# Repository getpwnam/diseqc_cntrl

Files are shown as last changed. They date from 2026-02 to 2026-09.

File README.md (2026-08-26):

# diseqc_cntrl

Ethernet-connected DiSEqC motor control interface for satellite LNB systems, built around an STM32F407 microcontroller.

## Disclaimer

This project is in development. No hardware or software testing has been performed and use in any way is at your own risk.

## Introduction

Enables remote control of LNB power supply voltage (13 V / 18 V polarization selection), DiSEqC 1.x command generation, and IF signal routing — all manageable over a 10/100 Mbps Ethernet link or USB.

## Repository Structure

The project is intentionally split into separate domains:

1. `hardware/`  
	KiCad schematics, PCB layout, fabrication outputs, and hardware-specific assets.
2. `software/nanoFramework/`  
	Managed application + native integration layer used by this project.
3. `nf-interpreter` (external dependency at build time)  
	The nanoFramework/ChibiOS firmware base is cloned during build and patched with this repository's target files.

See:
- `hardware/README.md`
- `software/README.md`
- `software/nanoFramework/README.md`

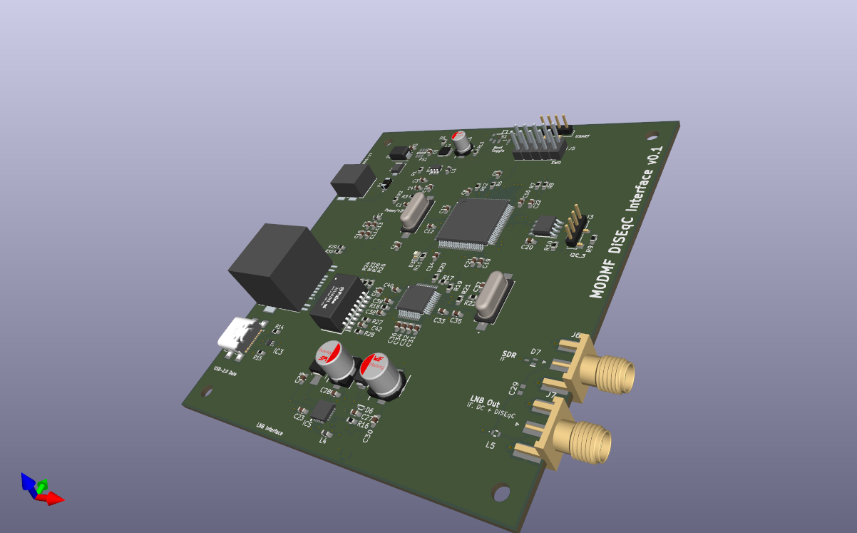
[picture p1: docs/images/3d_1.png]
3D render - top


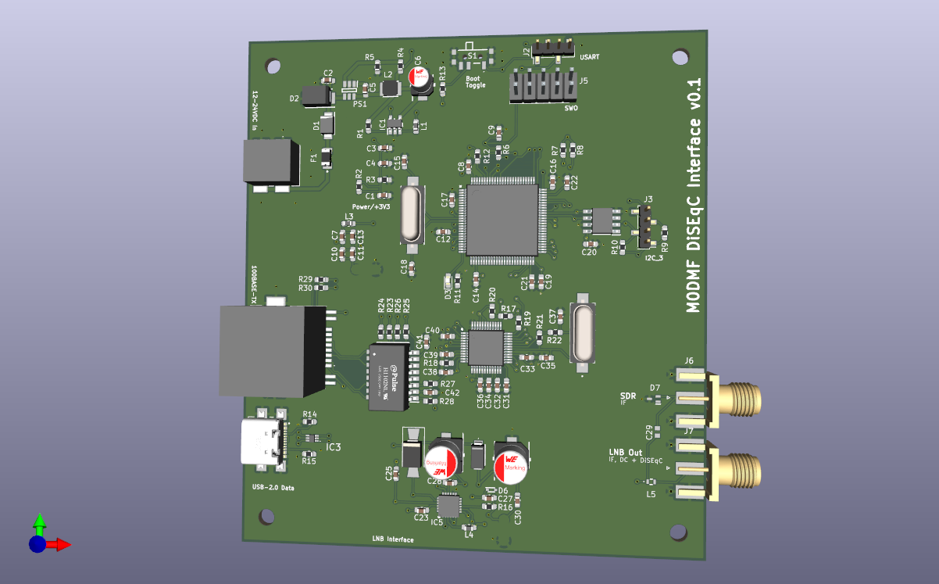
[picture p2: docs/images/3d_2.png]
3D render - perspective


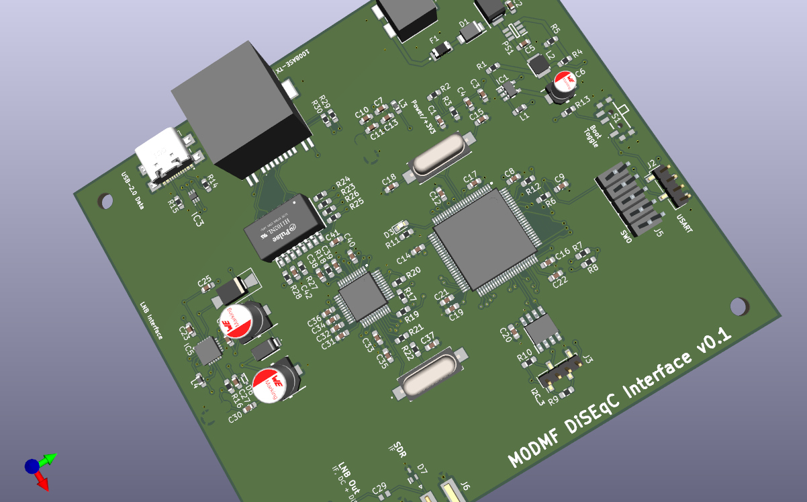
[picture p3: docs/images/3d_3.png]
3D render - bottom


## PCB

4-layer board (F.Cu / In1.Cu / In2.Cu / B.Cu) with split ground planes — digital GND, analog GNDA, and power PGND domains are connected via net ties at controlled star-ground points to minimise noise coupling into the LNB signal path.

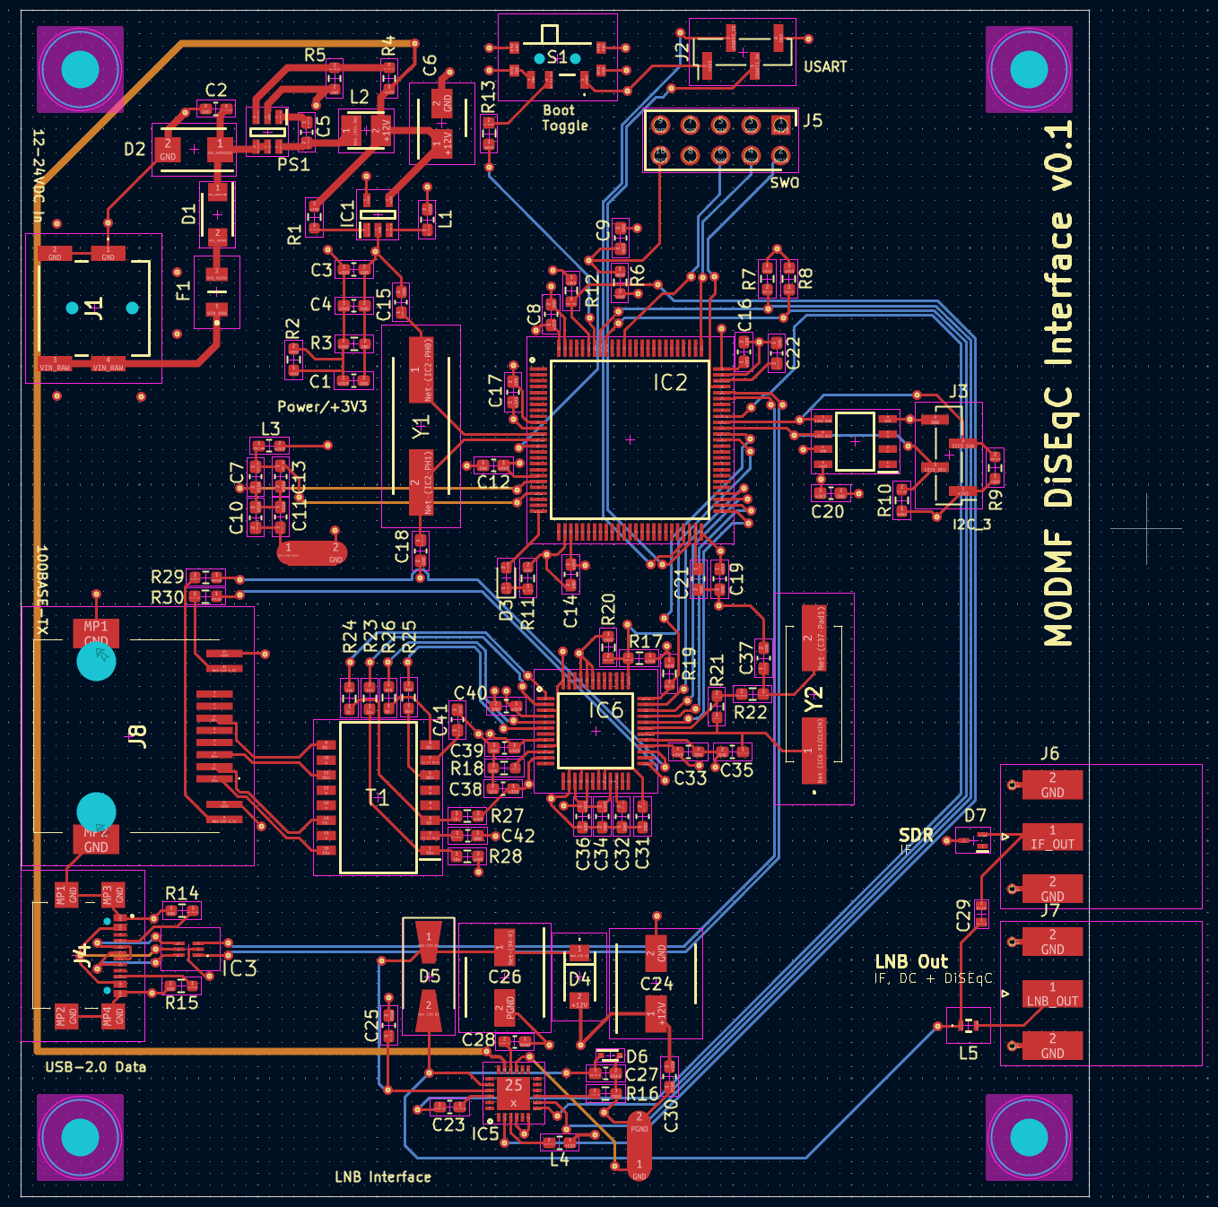
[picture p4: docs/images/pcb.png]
PCB layout


## Hardware Overview

### Microcontroller

- **STM32F407VGT6** (ARM Cortex-M4, 168 MHz, 1 MB Flash, 192 KB RAM, LQFP-100)
- 8 MHz HSE crystal (ABLS-8.000MHZ-20-B-3-H-T) on PH0/PH1 with C15/C18 load capacitors
- Separate filtered +3V3_ANA rail for the on-chip ADC reference
- Status LED (green, 0603)

### Key peripherals used

| Peripheral | Function |
| --- | --- |
| I2C1 | LNBH26PQR LNB supply controller |
| I2C3 | FM24CL16B 16 Kb F-RAM and expansion header |
| Ethernet MAC (RMII) | LAN8742A 10/100 Ethernet PHY |
| TIM4 CH1 | DiSEqC 22 kHz tone generation |
| USART3 | Serial debug / expansion (pin header J2) |
| USB OTG FS | USB 2.0 device (USB-C) |
| SWD | Debug port (2×5 pin header J5) |

### Power Supply

**Input:** Barrel jack (RASM742TRX, 2.1 mm centre-positive)

Protection chain (in order):

1. **F1** — PTC resettable fuse (1812L075/33DR, 0.75 A hold / 33 V)
2. **D2** — SMBJ24D bidirectional TVS (24 V clamp)
3. **D1** — SS14F-HF Schottky diode (reverse polarity protection)

Regulation:

| Stage | Device | Topology | Output |
| --- | --- | --- | --- |
| 1 | PS1 (TPS560430XDBVR) | Synchronous buck (4.3–36 V in) | +12 V (feeds LNBH26PQR) |
| 2 | TPS560200DBVR | Buck (4.5–17 V in) | +3.3 V (digital logic) |

A filtered +3V3_ANA rail is derived from +3.3 V via a ferrite bead for the MCU analog supply.

### LNB Control — LNBH26PQR

- Dual LNB supply regulator with integrated step-up converter (ST LNBH26PQR, QFN-24)
- Powered from the +12 V rail
- Generates switchable 13 V / 18 V output for LNB polarization selection
- Built-in DiSEqC 1.x/2.x 22 kHz tone modulation, driven from TIM4 CH1
- Fault output routed to MCU GPIO
- External boost components: STPS130A Schottky, US1A rectifier, 33 µH inductor, 100 µF bulk caps
- DiSEqC envelope detection via BAT43XV2 small-signal Schottky
- ESD protection on coaxial outputs (RCLAMP0502BATCT)

### Ethernet

- STM32F407 integrated 10/100 Ethernet MAC connected over RMII
- **LAN8742A-CZ-TR** 10/100 Ethernet PHY (Microchip, SQFN-24)
- 25 MHz PHY crystal (ABLS-25.000MHZ-D-FT)
- **J0011D21BNL** RJ45 connector with integrated magnetics and link/activity LEDs

### USB

- **USB4110-GF-A** USB Type-C receptacle (USB 2.0)
- **USBLC6-2P6** ESD protection on D+/D−
- Connected to STM32 USB OTG FS peripheral

### Non-Volatile Storage

- **FM24CL16B-GTR** 16 Kb F-RAM (Infineon, I2C, SOIC-8)
- Unlimited write endurance — stores network configuration, LNB settings, and DiSEqC sequence parameters

### Connectors

| Ref | Type | Purpose |
| --- | --- | --- |
| J1 | Barrel jack (RASM742TRX) | DC power input |
| J2 | 1×4 pin header (2.00 mm) | USART3 serial header (+3V3, TX, RX, GND) |
| J3 | 1×4 pin header (2.00 mm) | I2C3 expansion header (+3V3, SCL, SDA, GND) |
| J4 | USB-C (USB4110-GF-A) | USB 2.0 device |
| J5 | 2×5 pin header (2.54 mm) | SWD debug |
| J6 | SMA edge-mount | IF input from LNB |
| J7 | SMA edge-mount | LNB output (power + DiSEqC + IF) |
| J9 | RJ45 (J0011D21BNL) | 10/100 Ethernet with integrated magnetics and LEDs |
| S1 | SPDT slide switch (PCM12SMTBR) | Mode / power select |

### Test Points

| Ref | Net | Purpose |
| --- | --- | --- |
| TP1 | VIN_FUSED | Input rail after PTC fuse |
| TP2 | +12V | Main regulated 12 V rail |
| TP3 | +3V3 | Main digital logic rail |
| TP4 | VIN_RAW | Input rail before fuse/protection chain |
| TP5 | VIN_PROTECTED | Input rail after TVS and reverse-polarity diode |
| TP6 | +3V3_ANA | Filtered analog 3.3 V rail |
| TP7 | VSSA | Analog ground reference |
| TP8 | /MCU/BOOT0 | MCU BOOT0 strap node |
| TP9 | VBUS | USB VBUS (5 V) |
| TP10 | /MCU/CC1 | USB-C CC1 configuration channel |
| TP11 | /MCU/CC2 | USB-C CC2 configuration channel |
| TP12 | IF_OUT | IF signal path node |
| TP13 | LNB_OUT | LNB output node |
| TP14 | /MCU/LNBH26PQR/LNB_FLT | LNB controller fault signal |

### Protection

| Component | Type | Location |
| --- | --- | --- |
| F1 (1812L075/33DR) | PTC fuse, 0.75 A / 33 V | Power input |
| D2 (SMBJ24D) | 24 V bidirectional TVS | After fuse |
| D1 (SS14F-HF) | Schottky reverse polarity | After TVS |
| IC3 (USBLC6-2P6) | USB ESD clamp | USB D+/D− |
| D7 (RCLAMP0502BATCT) | ESD / CDE clamp | LNB coaxial I/O |

## Design Notes

- 4-layer PCB with split ground planes joined at star-ground net ties
- Predominantly 0603 passives throughout
- 3D models (STEP) provided for all major components
- Gerbers exported to `fab/gerber/`
- All Mouser part numbers embedded in schematic symbols for direct BOM procurement
- Crystal load-capacitor values are documented on schematic and periodically re-validated against crystal load specs and board parasitics

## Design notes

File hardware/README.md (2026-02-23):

# Hardware Domain

This directory contains the board design and fabrication assets for the DiSEqC controller.

## Contents

- `kicad-project/`
  - Source-of-truth schematics and PCB layout.
- `gerber/`
  - Fabrication outputs for PCB manufacturing.
- `nonfree/`
  - Third-party footprints/models/symbols and their licenses.
- `LICENSE.txt`
  - Hardware licensing information.

## Working Rules

- Treat KiCad files in `kicad-project/` as canonical.
- Regenerate Gerbers from the matching KiCad revision before manufacturing.
- Keep hardware-specific docs/assets in `hardware/` to avoid cross-domain drift.

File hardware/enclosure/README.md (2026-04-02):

# 3D Printed Enclosure (OpenSCAD)

This folder contains a first-pass printable enclosure for the DiSEqC controller PCB.

## Files

- `openscad/diseqc_enclosure.scad`
  - Parametric base + lid model.
  - Includes side-wall connector apertures for:
    - J1 barrel jack
    - J4 USB-C
    - J8 RJ45
    - J6/J7 SMA pair

## Known PCB Geometry Source

The enclosure defaults are based on:

- Board outline rectangle in KiCad: 90 x 100 mm
- Connector centroid positions from the PCB layout and production placement data

## Build Steps

1. Open `openscad/diseqc_enclosure.scad` in OpenSCAD.
2. Set `mode = "base"` and export STL.
3. Set `mode = "lid"` and export STL.
4. Slice with your preferred settings.

## Suggested Print Settings

- Material: PETG or ASA for outdoor/temperature resilience
- Layer height: 0.2 mm
- Perimeters: 4
- Top/Bottom layers: 5
- Infill: 20-30% gyroid
- Supports: none for base, optional for lid pocket depending on slicer

## Fit Calibration Workflow

1. Print base only.
2. Test PCB seating on ledges.
3. Check connector alignment in side apertures.
4. Tune these variables in the SCAD file:
   - `J1_y`, `J1_z`, `J1_w`, `J1_h`
   - `J4_y`, `J4_z`, `J4_w`, `J4_h`
   - `J8_y`, `J8_z`, `J8_w`, `J8_h`
   - `J67_y`, `J67_z`, `J67_w`, `J67_h`
5. Re-export and reprint base.
6. Once cutouts align, print lid.

## Notes

- This model intentionally uses PCB edge ledges instead of screw standoffs, because mounting-hole coordinates are not yet defined in this design package.
- If you want screw-down mounting, add hole coordinates from KiCad and convert ledges to standoffs in a follow-up revision.

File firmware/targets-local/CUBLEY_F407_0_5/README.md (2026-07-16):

## STM STM32F4DISCOVERY board

STM STM32F4DISCOVERY board

[Product page](http://www.st.com/en/evaluation-tools/stm32f4discovery.html)

The board used in this community contribution is the STM32F4DISCOVERY board from STM. The board can be purchased from various sources and should be about 20 euros. Further information on this board and links for the user and programming manuals can be found at the product page in ST [website](https://www.st.com/en/evaluation-tools/stm32f4discovery.html).

Some basic information abstracted from ST:

- STM32F407VGT6 microcontroller featuring 32-bit ARM®Cortex®-M4 with FPU core, 1-Mbyte Flash memory, 192-kbyte RAM in an LQFP100 package
- On-board ST-LINK/V2 on STM32F4DISCOVERY (old reference) or ST-LINK/V2-A on STM32F407G-DISC1 (new order code)
- USB ST-LINK with re-enumeration capability and three different interfaces:
  - Debug port
  - Virtual Com port (with new order code only)
  - Mass storage (with new order code only)
- Board power supply: through USB bus or from an external 5 V supply voltage
- External application power supply: 3 V and 5 V
- LIS302DL or LIS3DSH ST MEMS 3-axis accelerometer
- MP45DT02 ST-MEMS audio sensor omni-directional digital microphone
- CS43L22 audio DAC with integrated class D speaker driver
- Eight LEDs:
  - LD1 (red/green) for USB communication
  - LD2 (red) for 3.3 V power on
  - Four user LEDs, LD3 (orange), LD4 (green), LD5 (red) and LD6 (blue)
  - 2 USB OTG LEDs LD7 (green) VBUS and LD8 (red) over-current
- Two push-buttons (user and reset)
- USB OTG FS with micro-AB connector
- Extension header for all LQFP100 I/Os for quick connection to prototyping board and easy probing

## Flashing and debugging

This board has one mini USB connector exposing the embedded ST-Link interface that is used for flashing the nanoFramework firmware and for performing debugging on the nanoCLR code.
The second USB connector (a micro USB one) is used to connect the device with Visual Studio allowing to deploy and debug your C# managed applications.

## ADC configurations

The following ADC channels (and respective GPIO pins) are available to the managed API, in the respective index:

- PC1, ADC1 IN11
- PC2  ADC1 IN12
- PA6  ADC2 IN6
- PA7  ADC2 IN7
- PB0  ADC2 IN8
- Temp Sensor ADC1
- VrefInt ADC1
- Vbatt ADC1

## I2C configurations

I2C buses available:

- I2C1
  - SCL pin: GPIOB_8
  - SDA pin: GPIOB_9

## Floating point

The current build is set to add support for single-precision floating point.
Meaning that `System.Math` API supports only the `float` overloads. The `double` ones will throw a `NotImplementedException`.

## Firmware images (ready to deploy)



## Managed helpers

Checkout the [C# managed helpers](https://github.com/nanoframework/nf-Community-Targets/tree/main/ChibiOS/ST_STM32F4_DISCOVERY/managed_helpers) available for this board.

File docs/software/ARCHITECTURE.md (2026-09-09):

# Architecture Reference

## Purpose

Define the software boundaries, control flow, and ownership for the `software/nanoFramework` domain.

## Current Build Profile

- Target: `M0DMF_CUBLEY_F407`
- Build orchestrator: `toolchain/build-native.sh`
- Networking (`System.Net`): enabled for the device REST API
- Firmware outputs: `build/nanoCLR.bin`, `build/nanoCLR.hex`, `build/nanoCLR.elf`

## Layered Model

1. **Application Layer (C#)**
  - Location: `DiSEqC_Control/`
   - Responsibilities:
     - command routing
     - high-level rotor/LNB workflows
    - REST command and state interface

2. **Interop Layer (C++ bridge)**
   - Location: `nf-native/*_interop.cpp`
   - Responsibilities:
     - expose native functions to managed runtime
     - marshal arguments/results and status codes

3. **Native Driver Layer (C++/ChibiOS integration)**
  - Location: `nf-native/diseqc_native.*`, `nf-native/lnb_control.*`, `nf-native/board_cubley.*`
   - Responsibilities:
     - DiSEqC timing/control primitives
     - LNB I2C control (LNBH26PQR)
     - board-level pin/peripheral configuration

4. **Upstream Runtime Base (external)**
   - Location at build time: cloned `nf-interpreter`
   - Responsibilities:
     - nanoFramework runtime + ChibiOS target machinery
     - linker/toolchain integration

## Runtime Flows

### Control Flow

`Managed command` → `interop` → `native driver` → `board peripheral`

### Build Flow

`docker compose run ... /work/toolchain/build-native.sh` → clone/update `nf-interpreter` → copy static target files into `nf-interpreter/targets/ChibiOS/M0DMF_CUBLEY_F407/` → apply upstream compatibility patches → CMake/Ninja build → copy artifacts to `build/`

## Target File Ownership

All `M0DMF_CUBLEY_F407` target files are statically maintained in this repository under `nf-native/`:

| Directory | Contents |
|---|---|
| `nf-native/` | Board files: `board_cubley.h/cpp`, native drivers, interop sources |
| `nf-native/target-overrides/` | All ChibiOS/nf-interpreter integration files (halconf, chconf, linker scripts, CMakeLists.txt, mcuconf, target_*.c/cpp/h) |

The build script copies these files into the nf-interpreter target directory on each build. No reference-board fallback files are required. For the `cubley-stable` profile, `NF_STATIC_AUDIT=1` is enforced by default to verify this invariant at build time.

### Upstream Patches

The build script applies a small number of compatibility patches to nf-interpreter on each build:

- `CMake/Modules/FindChibiOS.cmake` — removes a duplicate include-path entry that causes double-compilation
- `CMake/binutils.common.cmake` — fixes `arm-none-eabi-size` invocation in generated ninja rules
- `targets/ChibiOS/_nanoCLR/CMakeLists.txt` — resets stale `INTERNAL` cache lists on re-configure
- `src/CLR/Startup/CLRStartup.cpp` — injects Cubley SWD-mailbox diagnostic hooks
- `src/CLR/Core/TypeSystem.cpp` — injects Cubley assembly-resolve diagnostic pointers

The first three are upstream bugs/limitations; the last two are board-specific diagnostics added during bring-up. All patches are idempotent (guarded by `grep -Fq` before applying).

## Hardware Integration Points

- DiSEqC carrier/timing: TIM-based output path (board-configured)
- LNB control: I2C (`LNBH26PQR`)
- Network path: STM32F407 internal Ethernet MAC over RMII with LAN8742A PHY
- Network application interface: REST v2 over HTTP

## Domain Boundaries

- This document describes `software/nanoFramework` only.
- PCB/schematic/fabrication ownership is in `hardware/`.
- `nf-interpreter` is an external dependency; this repo stores integration and build profile decisions, not a full fork layout.

## Related Documents (Software + Debug)

- `../README.md`
- `../debug/TESTING_GUIDE.md`
- `INTEROP_CONTRACT_V1.md`
- `INTEROP_VERSIONING_POLICY.md`
- `DEVICE_API_V2.md`
- `OBSERVABILITY_CONTRACT_V1.md`
- `CONFIGURATION.md`
- `../debug/LNB_I2C_TESTING.md`

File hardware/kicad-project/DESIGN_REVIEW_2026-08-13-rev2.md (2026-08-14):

# DiSEqC Controller Design Review, Revision 2

**Project:** `diseqc_cntrl` (KiCad 10 source, five hierarchical sheets, four-layer PCB)
**Review date:** 2026-08-13
**Review basis:** current unsuffixed KiCad source and current `production/` outputs; previous review conclusions were not used as evidence
**Verdict:** **Not ready for fabrication or assembly release.** No source-backed critical electrical blocker remains: STM32 `VREF+`, the D6 RClamp0502BA low-capacitance pin mode and direct-plane return, Ethernet MDI direction/polarity, RX orphan cleanup, and `REF_CLK` routing/transition stitching have been corrected. Release remains blocked by unresolved controlled impedance, unresolved stock, remaining open-via process requirements, incomplete finish/process metadata, and regeneration/validation of production outputs.

## Critical Findings

| Severity | Issue | Evidence and required action |
|---|---|---|
| High | Controlled impedances do not match interface targets | Raw-file and analytical verification using the declared 0.10 mm, εr=4.5 outer-layer dielectric and 35 um copper gives 45.6 Ω single-ended / approximately 84.9 Ω differential for the 0.12 mm / 0.20 mm-gap Ethernet MDI geometry, versus 100 Ω differential. Current 0.20 mm traces calculate to 36.2 Ω single-ended, affecting nominal 90 Ω USB, 50 Ω RMII, and 75 Ω IF routing. Obtain the fabricator stackup and field-solved geometries, then reroute and constrain each interface. |
| High | Assembly supply is incomplete | InvenTree matched 62 of 64 identity groups, but immediate unallocated stock is below one-board demand for IC1/IC2, IC4, D3–D6, L1–L3, multiple regulator capacitors/resistors, and one of two USB-C connectors. The production BOM has no manufacturer/supplier ordering fields. Resolve stock or purchase coverage and regenerate a traceable assembly BOM. |

## Previous Review Delta

This review was performed from source, production files, local PDFs, and fresh analyzer output before consulting prior reports.

| Status | Item |
|---|---|
| Resolved during review follow-up | IC3 pin 21 `VREF+` and PCB pad 21 now connect to the same `+3.3VA` rail as VDDA. The rail is fed through FB1 and decoupled by C18 (1 uF) and C21 (100 nF), consistent with STM32F407 Figure 52. |
| Resolved during review follow-up | D6 uses the RClamp0502BA low-capacitance one-line mode: pin 2=`IF_OUT`, pin 1=`GND`, and pin 3 open in both schematic and PCB. D6 is adjacent to the J7 launch; pin 2 has a 0.113 mm signal tap, and pin 1 reaches an off-pad 0.8/0.35 mm GND via through 1.10 mm of 0.20 mm F.Cu. The direct-plane return and via-in-pad warnings are resolved. |
| Resolved during review follow-up | All four exposed-pad thermal vias under each of IC1 and IC2 are explicitly bottom-tented (`front no`, `back yes`). Fresh analysis retains the thermal-via adequacy information and no longer reports solder-wicking warnings for these arrays. |
| Resolved during review follow-up | LAN8742 MDI direction and polarity now map directly: `TXP→TD+`, `TXN→TD-`, `RXP→RD+`, and `RXN→RD-`. Auto-MDIX/polarity correction is no longer required to compensate for PCB mapping. |
| Resolved during review follow-up | The isolated 0.508 mm RXN and 0.120 mm RXP B.Cu remnants are removed. Both nets are now F.Cu-only, have no signal vias, form one connected island each, and have no disconnected pads. |
| Resolved during review follow-up | GND stitching vias at both `REF_CLK` transitions now measure 0.950 mm center-to-center from their signal vias, with 0.150 mm copper-edge clearance. Fresh EMC analysis no longer emits `RP-001`. |
| Resolved during review follow-up | TP11, TP12, and TP16–TP24 were removed with their branch copper. This eliminates the IF_OUT, REF_CLK, MDC, MDIO, TX_EN, CRS_DV, and RMII data test branches; no segment terminates at a deleted pad coordinate. `REF_CLK` copper is now 16.344 mm and IF_OUT copper is 24.866 mm. |
| Still open | Controlled-impedance geometry, stock coverage, lifecycle uncertainty, CAM inspection, and physical electrical/thermal validation. |
| Confirmed resolved | L1/L2/L3 now have specific identities; regulator dividers resolve correctly with the manufacturer 1.000 V reference; current production Gerbers and drills are complete. |

## Design Overview

The board contains two LMR36520 bucks, an STM32F407VGT6, LNBH26PQR LNB/DiSEqC supply and IF extraction, LAN8742A RMII Ethernet with a J0011D21BNL integrated-magjack, native USB, FT230XS USB-UART, FM24CL16B FRAM, and SWD. Input protection includes a resettable fuse, reverse-polarity diode, and 24 V TVS. The PCB is 90 mm × 100 mm, 1.6 mm thick, with F.Cu / 0.10 mm prepreg / In1 GND / 1.24 mm core / In2 power / 0.10 mm prepreg / B.Cu.

## Component Summary

| Item | Result |
|---|---:|
| Schematic components | 157 total, 61 unique populated values, 3 intentional DNP |
| PCB footprints | 148, all placed on F.Cu; 121 SMD and 5 THT classified |
| Nets | 178 schematic; 170 PCB |
| Routing | 1,195 segments, 165 vias, zero reported unrouted nets |
| Zones | 7 filled zones; In1 GND is one 97%-filled region |
| Production BOM / placement | 121 populated BOM references; all 121 are positioned; placement also includes test, debug, net-tie, and fiducial references |
| Gerbers | 13 Gerber files plus PTH and NPTH drills; four copper layers, masks, pastes, silks, and edge cuts present |
| Drill output | 234 holes; X2-based classification and layer extents align |

The three cross-analysis “missing PCB” parts are expected: C9 and C10 are optional feedback capacitors marked DNP with no footprints, and R10 is DNP. This is not a synchronization defect.

## Power Tree and Regulator Review

```text
J1 VIN_RAW
  -> F1 resettable fuse -> VIN_FUSED
  -> D1 reverse-polarity protection + D2 24 V TVS -> VIN_PROTECTED
       -> IC1 LMR36520 + L1 33 uH -> +12V
            -> IC6 LNBH26 boost/linear channel -> 13/18 V LNB_OUT + IF extraction
       -> IC2 LMR36520 + L2 6.8 uH -> +3V3
            -> FB1 -> +3.3VA
            -> NT1 -> +3.3VP -> FB2 -> Ethernet 3V3_BEADED
USB J6 VBUS -> FB3 -> FT230_VCC
```

- **IC1:** R1=100 kΩ and R2=9.09 kΩ. With the LMR36520 1.000 V typical FB reference, $V_{OUT}=1.000(1+100/9.09)=12.00\text{ V}$. The analyzer's 7.20 V result used an incorrect heuristic 0.6 V reference and is rejected.
- **IC2:** R3=100 kΩ and R4=43.2 kΩ give $V_{OUT}=3.315\text{ V}$ nominal. The schematic analyzer missed this divider because of topology parsing.
- **Frequency:** LMR36520 is a fixed 400 kHz part per the manufacturer datasheet, not the analyzer's 500 kHz topology default.
- **Capacitance/inductance:** IC2's 6.8 uH and three 22 uF output capacitors agree with the datasheet's 3.3 V quick-start values. IC1's 33 uH and 4×10 uF plus bulk capacitance are plausible for 12 V but require load-transient verification at the actual VIN and load range.
- **LNBH26:** Pin numbering, I2C logic, 10 uH boost inductor, BYP capacitor, output bulk capacitor, and 27 nH/220 pF IF-isolation network are coherent with the local ST datasheet. The analyzer's 12 V/3.3 V I2C domain errors are false positives: SDA/SCL are logic pins rated independently of the IC's power output.

The actual maximum input voltage, rail loads, LNB current profile, and allowed ripple are not specified in the design files. A signed power budget remains required before release.

## PDN Impedance

The analytical model reports minima of 6.85 mΩ for +3V3 (66.6 uF, 1.58 MHz), 1.73 mΩ for +12V (140.2 uF, 1.58 MHz), 78.8 mΩ for +3.3VA (1.1 uF, 7.94 MHz), and 29.3 mΩ for Ethernet 3V3_BEADED (10.2 uF, 2.51 MHz). These are idealized lumped estimates using generic MLCC parasitics; mounting inductance, DC bias, ferrites, and plane spreading are not fully represented. Validate rail impedance/ripple at IC pins under load.

## Power Budget

The automated budget is incomplete and is not accepted quantitatively: it omits STM32 load, external loads, actual LNB output current, and USB operating states, and it carries the rejected 7.201 V IC1 estimate. It identifies the correct main consumers but only assigns 10 mA to LNBH26 and 100 mA to the PHY. Derive worst-case +12V and +3V3 budgets from firmware modes and external loads, then check converter, inductor, diode, trace, and connector margins.

## Power Sequencing

IC1 and IC2 EN pins are tied to `VIN_PROTECTED`, so +12V and +3V3 start together using each LMR36520's internal soft-start. Their open-drain PG pins are tied to GND and intentionally unused. No downstream rail-valid interlock exists; verify MCU brownout/reset behavior and LNB/PHY startup with simultaneous rails.

## Sleep Current Audit

The analyzer reports 1.42 mA always-on and 277.29 mA “realistic” sleep current, but 275.97 mA comes from treating conditional pull-ups as continuously asserted. That result is not credible without GPIO, PHY, FT230, and LNB states. Measure each supported firmware sleep mode; do not use the analyzer number for product power claims.

## Inrush Analysis

The lumped estimate is 1.01 A for 140.2 uF on +12V and 0.22 A for 66.6 uF on +3V3, assuming a 1 ms soft start. The +12V calculation also used the analyzer's incorrect 7.201 V value, so measure startup current and monotonicity at minimum/maximum VIN and with the intended LNB load.

## Analyzer Verification

### Datasheet and Pin Verification

Manufacturer PDFs in `.debug` were used directly. All analyzer-exposed complex components were compared from schematic pin number to PCB pad number: 278 of 284 normalized comparisons matched directly. The six residual names are intentional hierarchy aliases on the UART and duplicated USB-C VBUS pins; no physical pad mismatch was found.

| Device | Verification result |
|---|---|
| IC1/IC2 LMR36520ADDAR | Pins 1–9 and exposed-pad net mapping match TI Table 5-1. Feedback reference corrected to 1.000 V. |
| IC3 STM32F407VGT6 | LQFP100 pin numbering and RMII/USB/SWD alternate-function choices match the ST tables. Pin 21 `VREF+` and PCB pad 21 resolve to `+3.3VA`; C18 (1 uF) and C21 (100 nF) provide local reference decoupling. |
| IC4 FM24CL16B-GTR | SOIC-8 pin map, grounded WP, and I2C connections match the Infineon datasheet. |
| IC5 USBLC6-2P6 | Flow-through D+/D-, GND, and VBUS pin mapping matches the ST application circuit. The reported “no decoupling capacitor on IC5” is not a valid requirement for this protection array. |
| IC6 LNBH26PQR | QFN-25 pin map and exposed-pad ground match ST Table 2. Unused channel-B pins are treated consistently with the application. |
| IC7 LAN8742A-CZ-TR | VQFN-24 pin numbering, 12.1 kΩ RBIAS, 1 uF || 470 pF VDDCR bypass, supplies, crystal, and RMII pins match the Microchip datasheet. MDI direction/polarity mapping is now direct; impedance and return-path warnings remain as above. |
| U1 FT230XS-U | SSOP-16 pin map, TX/RX crossover, 3V3OUT/RESET/VCCIO network, and USB pins match FTDI documentation. |
| J9 J0011D21BNL | Exact Pulse J403 page-5 electrical schematic confirms PCB-side pins 1/2=`TD+/-`, 3/6=`RD+/-`, 4/5=center taps, 8=chassis. |
| D6 RClamp0502BA | The schematic and PCB map pin 2 to `IF_OUT`, pin 1 to GND, and pin 3 to an explicit no-connect, matching the datasheet's nominal 0.5 pF one-line mode. Pin 1 now connects directly to the GND planes through a coincident 0.8/0.35 mm via; electrically the return geometry is resolved. |
| Two-pin passives/mechanical parts | Pinout not meaningful; values and polarity were checked from topology and BOM where applicable. |

## Signal Analysis Review

No op-amp, bridge, battery, or isolated-power subcircuits are present. Detected regulator, divider, LC, protection, crystal, Ethernet, USB, I2C, UART, RMII, and SWD circuits were checked against raw connectivity. The principal accepted issues are controlled impedance, Ethernet/RMII return paths, and release-process constraints; the resolved IC3 `VREF+`, D6 electrical/assembly findings, IC1/IC2 bottom-tenting findings, and Ethernet MDI-mapping findings and rejected detector results are documented separately.

### Signal Integrity and Interfaces

### Differential pairs

| Pair | Lengths | Delta | Assessment |
|---|---:|---:|---|
| Ethernet TX | 18.042 / 15.131 mm | 2.911 mm | About 17 ps on FR-4; skew is modest, but nominal impedance is low. |
| Ethernet RX | 28.873 / 31.551 mm | 2.678 mm | About 16 ps; skew is modest. Both members are now entirely on F.Cu with no signal vias. |
| Native USB raw | 8.283 / 8.076 mm | 0.207 mm | Good matching. |
| Native USB protected | 31.535 / 32.405 mm | 0.870 mm | Good matching. |
| FT230 USB | 12.844 / 16.750 mm | 3.906 mm | Acceptable for USB full speed, but each line changes layer twice without adjacent return vias. |

### Controlled-Impedance Reverification

Fresh full PCB analysis was run after the reroute. Estimates use Wheeler/IPC-2141 single-ended microstrip equations and an edge-coupled microstrip approximation; they are geometry checks, not fabrication values. Solder mask, weave, copper roughness, actual cured dielectric thickness, and connector/package discontinuities require a 2D/3D field solve and coupon/TDR acceptance.

| Interface | Current geometry | Analytical estimate | Target and status |
|---|---|---:|---|
| Ethernet TX/RX MDI | F.Cu, 0.12 mm width, nominal 0.20 mm edge gap, 0.10 mm to In1 GND | 45.6 Ω single-ended; approximately 84.9 Ω differential on coupled runs | 100 Ω differential: **not met analytically**. Approximately 0.077 mm width at the same gap is a starting estimate only. |
| Native USB protected pair | F.Cu, 0.20 mm width, approximately 0.20 mm edge gap | 36.2 Ω single-ended; approximately 67.3 Ω differential | 90 Ω differential: **not met analytically**. Approximately 0.103 mm width at the same gap is a starting estimate only. |
| Native USB raw pair | F.Cu, 0.20 mm width, weak/variable coupling up to approximately 0.80 mm edge gap | 36.2 Ω single-ended; approximately 72.4 Ω differential when weakly coupled | 90 Ω differential: **not met analytically**; geometry is not uniform through the connector/ESD fanout. |
| FT230 USB pair | 0.20 mm width, mixed F.Cu/B.Cu, two transitions per net, not consistently coupled | 36.2 Ω single-ended; differential impedance is discontinuous and no more than approximately 72.4 Ω when uncoupled | 90 Ω differential: **not met analytically**. USB full-speed may tolerate this, but compliance is unverified. |
| RMII clock/data/control | 0.20 mm width, mixed outer layers on many nets | 36.2 Ω single-ended | Nominal 50 Ω routing: **not met analytically**. Approximately 0.095 mm width is a starting estimate; series resistors reduce source-reflection risk but do not set line impedance. |
| `IF_OUT` to J7 | 0.20 mm width, 24.866 mm total after TP11 removal, one transition, 87.5% sampled reference coverage | 36.2 Ω single-ended where referenced | 75 Ω: **not met analytically**. The approximately 0.023 mm calculated width is impractical, so change stackup/plane spacing and field-solve the route. |

Ethernet electrical mapping is correct and all four MDI pad-to-pad paths are connected entirely on F.Cu without signal vias. The former RX bottom-layer remnants and resulting RXP `RP-002` artifact are resolved. TP16–TP24 and their branch copper are removed. `REF_CLK` is now 16.344 mm total with 18/22 sampled points referenced; its four misses are at signal-via antipads rather than unsupported trace spans. Ethernet remains open for fabricator-approved 100 Ω MDI geometry and physical validation.

For a one-off non-compliance build, the impedance risk is lower than the formal release finding implies. The approximately 85 Ω Ethernet MDI pair has a first-order 1.18:1 VSWR against 100 Ω and is likely to link over ordinary cable; USB is full-speed and its short routes are likely to function; RMII routes are short, have 33 Ω source-series resistors, and no longer have test-point branches. The 950 MHz–2.15 GHz path through C40 is the material uncertainty: the approximately 36 Ω trace against a 75 Ω environment gives a first-order 2.07:1 VSWR and can introduce frequency-dependent loss/ripple. If only one impedance item is corrected before a hobby build, prioritize the LNB_OUT/IF_OUT path.

### External interfaces

- **J4 native USB-C:** 5.1 kΩ CC pulls and USBLC6 data protection are present. The closest GND via to IC5 is about 2.4 mm. VBUS power protection/inrush behavior should be checked against the intended host/device role.
- **J6 FT230 USB-C:** no dedicated external low-capacitance ESD array is present on D+/D-. Treat this as an EMC/robustness warning for a cable-facing port even if the IC's internal ratings are accepted.
- **J7 IF SMA:** D6 uses the correct nominal 0.5 pF connection and is adjacent to the launch. Pin 2's signal tap is 0.113 mm. Pin 1 reaches an off-pad 0.8/0.35 mm GND via at `(128.6, 131.0)` through 1.10 mm of 0.20 mm F.Cu. This resolves both the ESD-return inductance warning and the D6 solder-wicking warning.
- **J8 LNB SMA:** the 27 nH/220 pF feed/isolation network is present; validate insertion loss and DC-current behavior with the intended coax/load.
- **J9 Ethernet:** integrated 1:1 magnetics and chassis net are present. Earth is tied to GND by NT3; verify this hard tie is intentional for the enclosure and EMC strategy.

## USB Compliance

The analyzer records J4 data ESD as present and J6 as having no recognized external ESD array; it also flags VBUS decoupling on both ports. Its Type-C classifier incorrectly marks both USB4110-GF-A connectors as non-Type-C, so the aggregate pass/fail count is not accepted. Raw review confirms the CC terminations and J4 USBLC6 path. Resolve the J6 external-ESD decision and verify VBUS capacitance/inrush against the intended USB role.

## Bus Topology

Two I2C buses are present: STM32↔FRAM uses 2.7 kΩ pull-ups to +3V3, and STM32↔LNBH26 uses 4.7 kΩ pull-ups to +3V3. FT230 UART TX/RX is crossed correctly. RMII uses 33 Ω source-series resistors on data/control and clock, with 50 MHz `REF_CLK`. SWD/SWO is available at J5. No SPI or CAN bus is populated.

## SPICE Verification

`ngspice 44.2` was run on independently written passive models. Vendor switching models were not available, so regulator loop stability and transient response were not simulated.

| Circuit | Result |
|---|---|
| IC1 divider at 12 V | FB = 0.999908 V; consistent with 1.000 V regulation. |
| IC2 divider at 3.3 V | FB = 0.995531 V; consistent with a 3.315 V nominal setpoint. |
| LNB 27 nH / 200 nF / 220 pF network, ideal 75 Ω model | −0.012 dB at 22 kHz, approximately −88.0 dB at 950 MHz, and −109.3 dB at 2.15 GHz for the feed path. This supports DiSEqC pass-through and IF isolation in the ideal model. |
| D6 capacitance sensitivity, matched 75 Ω estimate | The corrected nominal 0.5 pF path gives approximately −0.27 dB at 2.15 GHz before package/layout parasitics; the former 1.2 pF path would have been approximately −1.37 dB. |

## PCB Layout Analysis

## EMC / Cross-Domain Analysis

### Ground, return paths, and EMC

The raw EMC score is 0/100 from 111 findings, but it is not a calibrated board score. The analyzer incorrectly classified every adjacent copper layer as a signal layer and fragmented thermal-relief/connector pads despite the 97%-filled one-region In1 GND zone and zero-unrouted result. The broad `SU-001`, `GP-001`, and plane-island counts are therefore not accepted as blockers.

Retained EMC risks:

1. FT230 D+/D- and SWD clock change layers without local return vias. USB full-speed timing is tolerant, but common-mode conversion can increase emissions.
2. The barrel input has surge/reverse protection but no dedicated conducted-EMI input filter. Test 400 kHz converter fundamentals/harmonics on the input cable under maximum load.
3. Ethernet MDI mapping, RX copper cleanup, and `REF_CLK` routing/stitching are corrected, but nominal MDI impedance is approximately 85 Ω rather than 100 Ω.
4. D6's pin mode is corrected; its narrow RF/ESD return still requires layout improvement or validation.
5. Cable-attached pre-compliance testing should cover 30 MHz–1 GHz with Ethernet, both USB ports, and representative LNB coax attached.

Positive geometry includes a near-solid In1 GND reference, 61 GND stitching vias, short crystal-local networks, complete routing, and local power islands on In2.

### Thermal

The automated thermal pass analyzed only IC1 at an assumed 13 mW and reported 25.8 °C. That is not a credible board-level worst case and is treated as a coverage gap.

- IC1 and IC2 each have four 0.35 mm drilled GND vias in exposed pad 9.
- IC6 has four 0.35 mm drilled GND vias in exposed pad 25. LNBH26 specifies the exposed pad connected to power ground and ground layer through vias; datasheet $R_{\theta JA}$ is 40 °C/W on a 2s2p board with thermal vias.
- IC7 has a 3×3 exposed-pad via pattern using footprint micro-holes; this is a good geometric pattern, subject to fabricator capability.
- The IC1/IC2/IC6 vias are open through-vias. Copper transfer is adequate, but solder wicking and voiding require filled/capped vias or a qualified stencil/paste process.

Perform thermal validation at maximum VIN, maximum +3V3 load, and maximum supported 13/18 V LNB current. Record IC1, IC2, IC6, L1–L3, diode, and connector temperatures after equilibrium.

## Gerber Verification

The extracted production ZIP contains all four copper layers, both masks, both paste layers, both silks, edge cuts, and separate PTH/NPTH drills. X2 extents align, edge cuts are closed at 90 mm × 100 mm, and 234 holes are classified. The four B.Paste flashes belong to J7/J8 and are an assembly-process choice, not missing data. Source-to-Gerber net-level equivalence cannot replace a regenerated post-fix CAM comparison.

## Manufacturing and DFM

- Production Gerbers are complete and aligned at 90 mm × 100 mm. PTH and NPTH drill files are present.
- Minimum trace is 0.12 mm, minimum drill 0.20 mm, and minimum annular ring 0.15 mm. The installed analyzer labels 0.12 mm as an advanced-process feature; obtain written fabricator acceptance.
- Four open vias occur in each LMR/LNB exposed pad. D2 and USB-C shell-pad vias also trigger solder-wicking warnings. Define via fill/cap/tent requirements explicitly in fabrication notes and quote options.
- B.Paste contains four deliberate flashes on J7/J8 bottom shell pads although all placed components are top-side. A top-only stencil will not deposit these apertures. Define whether the SMA shells are hand-soldered, selectively pasted, or require a bottom stencil/process.
- J1, J4, J6, J7, J8, and J9 courtyard overhangs are connector mechanics, not placement errors. C36, F1, SW1, TP1, and TP2 are also close to the edge; confirm panel rails, depanel clearance, and enclosure access.
- Project copper-to-edge and silk-clearance minima are 0.0 mm. Add explicit production constraints rather than relying on the fabricator's defaults.
- Surface finish is recorded as `None` in the project stackup. Specify finish, copper weight, mask color, controlled-impedance stackup, acceptance tolerance, and via treatment on the order/drawing.
- Four DRC exclusions cover the mounting-hole “extra footprint” checks only. Footprint filter/type mismatch and missing-courtyard checks are ignored globally; no critical connectivity rule is disabled.

## Sourcing and Lifecycle

InvenTree enrichment found 62 matched identity groups, two conflicts, no not-found records, no API errors, and no populated component lacking an identity. Numeric IDs make the two conflicts traceable but they should be corrected:

- R20 schematic name `R_20k_0603` versus InvenTree `R_20k_0603_1%`.
- SW1 schematic name `W_PUSH_MOMENT_SMD` versus InvenTree `SW_PUSH_MOMENT_SMD`.

The lifecycle audit queried 19 schematic MPNs and returned `unknown` for all 19. InvenTree marks matched records active, but this is internal status rather than manufacturer lifecycle proof. Recheck manufacturer lifecycle and supplier availability before purchasing. Stock fields with zero or stale supplier availability are not proof of market unavailability, but they do block an immediate internal build.

## Test Coverage

There are 12 named test points covering input/protected power, +12V, +3V3, VBUS, reset/boot, LNB fault/DiSEqC, and both LNB I2C lines; SWD is exposed at J5. No RMII, REF_CLK, Ethernet MDI, USB, or IF_OUT test branches remain. Do not add direct probes to feedback/switch nodes or other high-speed nets unless a production or certification requirement justifies the discontinuity.

## Assembly Complexity

The schematic heuristic scores assembly at 35/100 with two QFN-class hard parts, one LQFP100, dense 0603 usage, and 41 unique footprints. Hand assembly may be feasible for prototypes, but repeatable production needs stencil control for QFN/power pads, a defined process for open thermal vias, and explicit J7/J8 bottom-shell soldering.

## BOM Optimization

The analyzer finds 13 resistor values, 14 capacitor values, and 16 single-use passive values. Do not consolidate regulator, crystal, Ethernet, USB, or LNB parts solely by nominal value; voltage rating, dielectric, tolerance, ESR, DCR, saturation/ripple current, Q, and package parasitics are functional requirements. Optimization is secondary to completing the traceable MPN BOM.

## False Positives and Reviewer Overrides

- `VM-001` SDA/SCL 12 V to 3.3 V crossings: rejected; LNBH26 I2C pins are logic-domain pins.
- `XV-001` C9/C10/R10 missing from PCB: rejected; all are intentional DNP.
- `SU-001` all copper layers are adjacent signal layers: rejected; In1 is the GND plane and In2 is power distribution.
- GND/+3V3/+3.3VA multi-island blocker counts: downgraded because the graph splits pads connected through thermal reliefs and connector structures; source reports one filled GND region and zero unrouted nets. Native KiCad DRC is still required after changes.
- Connector edge-overhang findings: accepted as intentional mechanics, pending panel/enclosure verification.
- Gerber `GR-004` bottom paste ratio: not a missing-paste defect; the four flashes belong to J7/J8. It remains an assembly-process requirement.
- IC5 missing decoupling: rejected; USBLC6's VBUS pin is a protection reference, not an IC supply requiring local bypass in the cited application.
- IC1/C3/L1 “large hot loop”: rejected as selected-component misassociation; C3 is not the local IC1 input-loop capacitor.

## Not Performed / Review Limits

- **Fresh native ERC/DRC:** not run because `kicad-cli` is unavailable. Prior manual results were not accepted as fresh evidence. Rerun KiCad ERC and DRC after the IC3 and D6 pin corrections and any D6 return-path change.
- **Vendor-model switching SPICE:** not performed; no LMR36520 or LNBH26 encrypted/vendor models were available. Passive and feedback simulations were performed with ngspice.
- **Full thermal solution:** not possible without actual rail loads, ambient/enclosure conditions, copper-emissivity assumptions, and package power. The installed thermal analyzer's one-device estimate is inadequate.
- **Field-solver impedance:** not performed. Analyzer estimates are geometry checks only; fabricator impedance modeling/coupons are required.
- **Lifecycle certainty:** network audit returned unknown for every direct MPN.
- **Lab validation:** no oscilloscope, VNA/TDR, load transient, Ethernet packet, USB compliance, ESD, thermal-camera, or EMC measurements were performed.
- **Deep structured extraction:** no `datasheets/extracted/` cache exists; critical checks used direct local manufacturer PDFs.

## Release Checklist

1. Obtain a controlled-impedance stackup and field-solved geometries for 100 Ω Ethernet, 90 Ω USB, 50 Ω RMII, and 75 Ω IF; update netclasses and reroute as required.
2. Rerun native KiCad ERC/DRC, refill zones, regenerate all production outputs, and compare checksums/CAM plots; include the corrected IC3, D6, and Ethernet mappings in the review.
3. Specify surface finish, copper weight, remaining via fill/cap/tent requirements, and J7/J8 bottom-paste assembly process; preserve IC1/IC2 bottom-only thermal-via tenting in regenerated mask outputs.
4. Close InvenTree conflicts and stock shortfalls; generate an MPN/manufacturer/supplier assembly BOM.
5. Validate both bucks and LNB supply at worst-case VIN/load, including startup, ripple, load transient, and temperature.
6. Run Ethernet link/packet tests with forced and autonegotiated modes, USB functional tests, ADC accuracy tests, IF insertion/return loss, and ESD/EMC pre-compliance.

## Final Verdict

**Not ready for fabrication or assembly release.** STM32 `VREF+`, D6 pin mode/direct-plane return/via placement, IC1/IC2 bottom thermal-via tenting, Ethernet MDI direction/polarity, RX orphan-copper cleanup, and RMII `REF_CLK` routing/stitching are corrected. The current MDI geometry still estimates near 85 Ω differential rather than 100 Ω; USB, RMII, and IF geometries also miss their nominal impedance targets analytically. Obtain fabricator-solved geometries, then repeat ERC/DRC, production generation, impedance/coupon review, and physical validation before ordering.

## Analyses Run

- `analyze_schematic.py` on the root hierarchical schematic
- `analyze_pcb.py --full --proximity` on the current PCB
- `cross_analysis.py` on fresh schematic and PCB JSON
- `analyze_gerbers.py --full` on the extracted production ZIP
- `analyze_thermal.py` (coverage limitation documented)
- `analyze_emc.py --market eu --spice-enhanced` (wrapper failed to detect installed ngspice; analytical output was triaged manually)
- `ngspice 44.2` independent divider and LNB filter simulations
- `analyze_schematic.py --lifecycle`
- InvenTree exact-identity enrichment
- Raw schematic/PCB pin-pad comparison, project-rule audit, production BOM/placement cross-check, and direct PDF verification

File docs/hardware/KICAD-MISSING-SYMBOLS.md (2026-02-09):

# Non-free KiCad Assets

This project uses non-free content (e.g., vendor-specific footprints,
licensed models, or redistributable-but-not-open assets). This content is expected in the directory structure:
```
hardware/kicad-project/nonfree/
    3dmodels/
        *.stp

    footprints/
        <PROJECTNAME>.pretty

    symbols/
        <PROJECTNAME>.kicad_sym
```

The content is stored in a private Git submodule:
  https://github.com/getpwnam/m0dmf_kicad_nonfree

## How to fetch it

### Component Search Engine

All of the required symbols are available from https://componentsearchengine.com
You'll just need to fetch them yourself and copy them into the appropriate directories shown above.

### If you have access to the submodule

To install:
`git submodule update --init --recursive`

To update / pin most recent revision:
```bash
git pull                          # update main repo
git submodule update --init       # ensure submodule loaded
git submodule update --remote     # fetch latest private content
```

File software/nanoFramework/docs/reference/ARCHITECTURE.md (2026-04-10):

# Architecture Reference

## Purpose

Define the software boundaries, control flow, and ownership for the `software/nanoFramework` domain.

## Current Build Profile

- Target: `M0DMF_CUBLEY_F407`
- Build orchestrator: `toolchain/build.sh`
- Networking (`System.Net`): **disabled** in the currently validated profile
- Firmware outputs: `build/nanoCLR.bin`, `build/nanoCLR.hex`, `build/nanoCLR.elf`

## Layered Model

1. **Application Layer (C#)**
  - Location: `DiSEqC_Control/`
   - Responsibilities:
     - command routing
     - high-level rotor/LNB workflows
     - state publication/integration glue

2. **Interop Layer (C++ bridge)**
   - Location: `nf-native/*_interop.cpp`
   - Responsibilities:
     - expose native functions to managed runtime
     - marshal arguments/results and status codes

3. **Native Driver Layer (C++/ChibiOS integration)**
  - Location: `nf-native/diseqc_native.*`, `nf-native/lnb_control.*`, `nf-native/board_cubley.*`
   - Responsibilities:
     - DiSEqC timing/control primitives
     - LNB I2C control (LNBH26PQR)
     - board-level pin/peripheral configuration

4. **Upstream Runtime Base (external)**
   - Location at build time: cloned `nf-interpreter`
   - Responsibilities:
     - nanoFramework runtime + ChibiOS target machinery
     - linker/toolchain integration

## Runtime Flows

### Control Flow

`Managed command` → `interop` → `native driver` → `board peripheral`

### Build Flow

`docker compose run ... /work/toolchain/build.sh` → clone/update `nf-interpreter` → inject target/integration files → CMake/Ninja build → copy artifacts to `build/`

## Hardware Integration Points

- DiSEqC carrier/timing: TIM-based output path (board-configured)
- LNB control: I2C (`LNBH26PQR`)
- Optional network path (when enabled): W5500 over SPI

## Domain Boundaries

- This document describes `software/nanoFramework` only.
- PCB/schematic/fabrication ownership is in `hardware/`.
- `nf-interpreter` is an external dependency; this repo stores integration and build profile decisions, not a full fork layout.

## Related Documents

- `../README.md`
- `../../QUICK_START.md`
- `../guides/DOCKER_BUILD_GUIDE.md`
- `../guides/TESTING_GUIDE.md`
- `MQTT_API.md`
- `CONFIGURATION.md`
- `../hardware/W5500_ETHERNET.md`
- `../hardware/LNB_I2C_TESTING.md`
- `../hardware/MOTOR_ENABLE_NOTES.md`

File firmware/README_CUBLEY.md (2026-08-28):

# CUBLEY_F407_0_5 Firmware Reference

This document summarizes the current Cubley firmware board configuration for:

- pin config and ownership
- active runtime transport mode
- CubleyNative interop surface

It is intended as a quick reference for bring-up and firmware changes.

## Quick Start
```sh
./bootstrap.sh
./build-flash-cubley.sh build
```

## Scope and Source of Truth

Primary code sources:

- `firmware/targets-local/CUBLEY_F407_0_5/board.h`
- `firmware/targets-local/CUBLEY_F407_0_5/target_common.c`
- `firmware/targets-local/CUBLEY_F407_0_5/common/serialcfg.h`
- `firmware/targets-local/CUBLEY_F407_0_5/CMakeLists.txt`
- `firmware/targets-local/CUBLEY_F407_0_5/nanoCLR/cubley_interop.cpp`
- `firmware/targets-local/CUBLEY_F407_0_5/nanoCLR/lnbh26_interop.cpp`

Supporting docs used for pin audit history and baseline context:

- `docs/debug/BOARD_PIN_OWNERSHIP_AUDIT.md`
- `docs/debug/PHASE_A_BASELINE.md`
- `docs/software/INTEROP_CONTRACT_V1.md`

## Runtime Mode (Current)

### Wire protocol transport

- Wire protocol transport: USART3 on PD8 (TX) and PD9 (RX)
- nanoFramework DebuggerPort: COM3
- Wire protocol baud: 921600
- DebugTextPort: disabled (prevents `hal_printf()` traffic from interleaving with wire protocol)

Source:

- `target_common.c` (`HAL_SYSTEM_CONFIG`)
- `common/serialcfg.h` (`SERIAL_DRIVER SD3`)

### USB CDC mode

USB CDC console support can be compiled in (`UsbCdcConsole` interop exists), but wire protocol remains on UART by design.

- Build forces `WireProtocol_ReceiverThread.c` with `HAL_USE_SERIAL_USB=FALSE`
- Result: USB CDC does not become the wire protocol transport

Source:

- `CUBLEY_F407_0_5/CMakeLists.txt`
- `nanoCLR/cubley_interop.cpp`

## Pin Config and Ownership

`board.h` uses a staged model:

- Phase 0: board-owned peripheral pins default to input + pull-up (safe state)
- Later phases: pins are switched to required AF/output modes as subsystems come up

### Active ownership table

| Pin | Net | Function | Owner | Mode/AF |
|---|---|---|---|---|
| PA1 | /MCU/REF_CLK | RMII REF_CLK | board init | AF11 |
| PA2 | /MCU/MDIO | RMII MDIO | board init | AF11 |
| PA7 | /MCU/CRS_DV | RMII CRS_DV | board init | AF11 |
| PC1 | /MCU/MDC | RMII MDC | board init | AF11 |
| PC4 | /MCU/RXD0 | RMII RXD0 | board init | AF11 |
| PC5 | /MCU/RXD1 | RMII RXD1 | board init | AF11 |
| PB11 | /MCU/TX_EN | RMII TX_EN | board init | AF11 |
| PB12 | /MCU/TXD0 | RMII TXD0 | board init | AF11 |
| PB13 | /MCU/TXD1 | RMII TXD1 | board init | AF11 |
| PB0 | /MCU/LED_STATUS | status LED | board init + interop | GPIO output push-pull |
| PB6 | /MCU/I2C1_SCL | I2C1 SCL (FRAM bus) | board init | AF4 open-drain + pull-up |
| PB7 | /MCU/I2C1_SDA | I2C1 SDA (FRAM bus) | board init | AF4 open-drain + pull-up |
| PA8 | /MCU/I2C3_SCL | I2C3 SCL (LNB bus) | board init | AF4 open-drain + pull-up |
| PC9 | /MCU/I2C3_SDA | I2C3 SDA (LNB bus) | board init | AF4 open-drain + pull-up |
| PC8 | /MCU/LNB_FLT | LNB fault input | board init | input + pull-up |
| PD8 | /MCU/USART3_TX | wire protocol TX | serial transport | AF7 |
| PD9 | /MCU/USART3_RX | wire protocol RX | serial transport | AF7 |
| PD12 | /MCU/TIM4_CH1 | DiSEqC output | board init | AF2 |
| PD14 | /MCU/TIM4_CH3 | motor/PWM helper | board init | AF2 |
| PD15 | /MCU/TIM4_CH4 | motor/PWM helper | board init | AF2 |

Notes:

- PB8/PB9 are no-connect on this board revision.
- FRAM device is on I2C1 (PB6/PB7).
- SWD is on PA13/PA14; SWO is PB3.

## CubleyNative Interop Surface (Current Native Table)

Native assembly export in `nanoCLR/cubley_interop.cpp`:

- Assembly: `CubleyNative`
- Native checksum: `0x0A4353F9`
- Version tuple: `{ 1, 0, 0, 0 }`

Method slot map (native `method_lookup`):

| Slot | Native API |
|---:|---|
| 0 | `DiagMailbox.NativeSet(uint)` |
| 1 | `DiagMailbox.NativeGet()` |
| 2 | `DiagMailbox.NativeGetLastNativeError()` |
| 3 | `Fram24C128.NativeInit()` |
| 4 | `Fram24C128.NativeWrite(int, byte[], int, int)` |
| 5 | `Fram24C128.NativeRead(int, byte[], int, int)` |
| 6 | `LNBH26.NativeInit()` |
| 7 | `LNBH26.NativeSetEnable(int, bool)` |
| 8 | `LNBH26.NativeReadStatus(out int)` |
| 9 | `LNBH26.NativeReadStatusPair(out int, out int)` |
| 10 | `LNBH26.NativeSetPolarizationForChannel(int, int)` |
| 11 | `LNBH26.NativeSetBandForChannel(int, int)` |
| 12 | `LNBH26.NativeSetLowPowerForChannel(int, bool)` |
| 13 | `LNBH26.NativeSetDiseqcInputModeForChannel(int, int)` |
| 14 | `LNBH26.NativeGetPolarizationForChannel(int)` |
| 15 | `LNBH26.NativeGetBandForChannel(int)` |
| 16 | `LNBH26.NativeGetLastError()` |
| 17 | `LNBH26.NativeGetLastErrorDetail()` |
| 18 | `LNBH26Registers.NativeReadRegister(int, out int)` |
| 19 | `LNBH26Tweaks.NativeSetIsetLowForChannel(int, bool)` |
| 20 | `LNBH26Tweaks.NativeSetIswLowForChannel(int, bool)` |
| 21 | `LNBH26Tweaks.NativeGetIsetLowForChannel(int)` |
| 22 | `LNBH26Tweaks.NativeGetIswLowForChannel(int)` |
| 23 | `UsbCdcConsole.NativeIsEnabled()` |
| 24 | `UsbCdcConsole.NativeReadByte(int)` |
| 25 | `UsbCdcConsole.NativeWrite(string)` |
| 26 | `ZPersistentConfiguration.NativeRead(byte[], int, int)` |
| 27 | `ZPersistentConfiguration.NativeWrite(byte[], int, int)` |
| 28 | `ZZDiseqcTransmitter.NativeTransmit(byte[], int, int)` |
| 29 | `ZZDiseqcTransmitter.NativeSetTone(int, int, bool)` |

### Interop ownership and update rules

- Keep emitted PE method order and native `method_lookup` order aligned.
- Do not reorder or repurpose existing slots.
- Add a method only when the emitted PE order preserves the frozen 26-slot prefix.
- Recompute and validate checksum after interop changes.

See `docs/software/INTEROP_CONTRACT_V1.md` for policy and process.

## DiSEqC timer ownership

- TIM4 and PD12/TIM4_CH1 are owned by the native DiSEqC transmitter for the
	continuous 22 kHz tone and frame carrier. Other code must not reconfigure
	TIM4 while DiSEqC support is active because its period is shared by all
	TIM4 channels.
- TIM6 is owned by the native DiSEqC transmitter as a 1 MHz one-shot
	mark/space boundary scheduler. It has no external pin requirement.
- TIM2 remains reserved for the ChibiOS system timer and must not be used by
	the DiSEqC transmitter.
- A frame call blocks its calling managed thread with a bounded 250 ms wait;
	carrier gating and completion are interrupt-driven. Continuous tone is
	restored only after the managed 15 ms post-frame quiet interval.

## Diagnostics Words

Current native diagnostics globals (in `cubley_interop.cpp`):

- `g_cubley_diag_current_status`: transient status word
- `g_cubley_diag_last_error`: latest native error/detail word

`lnbh26_interop.cpp` and FRAM wrappers update `g_cubley_diag_last_error` with subsystem-specific encoded values for bring-up debugging.

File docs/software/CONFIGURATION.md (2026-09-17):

# Configuration Reference

## Configuration Domains

CubleyControl has two persisted configuration domains:

- **Network**: IPv4 assignment and DNS in the standard nanoFramework network
  configuration block.
- **Application**: hostname and DiSEqC positioning calibration in the portable
  512-byte schema-5 application record described in
  [CONFIGURATION_STORAGE.md](CONFIGURATION_STORAGE.md).

Configuration is changed only through the USB CDC console. The REST API does
not expose configuration operations.

## Defaults

### Network

| Setting | Default |
|---|---|
| Address mode | DHCP |
| Static address, mask, gateway | `0.0.0.0` |
| DNS mode | Automatic |
| Static DNS servers | `0.0.0.0` |

### Application Schema 5

| Setting | Default | Valid values |
|---|---|---|
| Hostname | Automatic | Empty/`auto`, or a lowercase DNS label up to 63 characters using `a-z`, `0-9`, and internal hyphens |
| API token | Disabled | Empty, or 32-64 characters from `a-z`, `A-Z`, `0-9`, `-`, `_`, `.`, `~` |
| East angle limit | Disabled | `0`, or greater than 0 through 180 degrees |
| West angle limit | Disabled | `0`, or greater than 0 through 180 degrees |
| East step calibration | Disabled | `0`, or greater than 0 through 180 degrees per step |
| West step calibration | Disabled | `0`, or greater than 0 through 180 degrees per step |
| Signed GoToX offset | `0` | West 180 degrees through east 180 degrees |

East/west limits and east/west step calibration are each configured as a pair:
both values must be zero or both must be positive. Values are stored as integer
microdegrees. An automatic hostname resolves to `cubley-xxxxxx` from the STM32
unique device ID, or `cubley` if the ID is unavailable.

## USB CDC Configuration Mode

Enter configuration mode with `configure`, `config`, or `conf`; an optional
`terminal`/`t` token is accepted. Changes are staged in RAM until `commit`.

```text
cubley-a1b2c3> configure
cubley-a1b2c3(config)# hostname <name|auto>
cubley-a1b2c3(config)# api-token set <token>
cubley-a1b2c3(config)# api-token clear
cubley-a1b2c3(config)# network mode <dhcp|static>
cubley-a1b2c3(config)# network address <ipv4>
cubley-a1b2c3(config)# network mask <mask>
cubley-a1b2c3(config)# network gateway <ipv4>
cubley-a1b2c3(config)# network dns auto
cubley-a1b2c3(config)# network dns static <dns1> [dns2]
cubley-a1b2c3(config)# diseqc angle-limits <east> <west>|off
cubley-a1b2c3(config)# diseqc step-calibration <east> <west>|off
cubley-a1b2c3(config)# diseqc fixed-offset <east|west> <degrees>|off
cubley-a1b2c3(config)# show candidate-config [network|application|diseqc|all]
cubley-a1b2c3(config)# show running-config [network|application|diseqc|all]
cubley-a1b2c3(config)# show startup-config [network|application|diseqc|all]
cubley-a1b2c3(config)# show config diff
cubley-a1b2c3(config)# show storage
cubley-a1b2c3(config)# debug <on|off>
cubley-a1b2c3(config)# commit
cubley-a1b2c3(config)# discard
cubley-a1b2c3(config)# exit
```

`network defaults`, `diseqc defaults`, `load defaults [domain]`, and
`defaults [domain]` stage defaults. Supported domains are `network`,
`application`, `diseqc`, and `all`.

The prompt becomes `<hostname>(config*)#` while the candidate differs from the
running configuration. It continues to use the committed hostname until commit
succeeds. `exit`, `end`, and empty-line `Ctrl+D` refuse to leave configuration
mode while changes are pending. Use `commit` or `discard` explicitly.

`show running-config` omits default-valued lines. Startup and candidate views
render complete selected domains under a `! cubley-config v5 <source>` header.
Configured API token values are rendered in cleartext and token-setting commands
are retained in command history. Protect console access and captured output.
Tokens must contain 32 to 64 characters from `A-Za-z0-9._~-`;
`openssl rand -hex 32` generates a suitable token.
`show storage` reports network and application backend/load status. `debug on`
shows successful setter details for the current USB session; failures are always
shown.

## Runtime Overrides

Operational `diseqc angle-limits <east> <west>` and `diseqc angle-limits off`
write the application record immediately and survive reboot. The runtime limits
change only after the write is verified. Operational `diseqc step-calibration`
commands remain RAM-only, and the fixed GoToX offset is changed only in
configuration mode.

The signed offset is applied before direction-specific limit checking and GoToX
encoding. For example, `diseqc fixed-offset west 3.38` changes a requested
36.6 degrees east to an effective 33.22 degrees east before protocol rounding.

The offset is an internal calibration factor. Reported positions stay in the
signed USALS domain, so the example above is reported as 36.58 degrees east
after protocol rounding, and the offset-adjusted motor angle is visible only in
USB `show diseqc detail`. The 0.02 degree difference between the entered and
reported angle is the 0.1 degree GoToX quantization; USB `show diseqc` reports it
as "Protocol rounding (estimate - request)".

## Commit And Recovery

`commit` validates the complete network and application candidates before
writing changed domains. The application write updates internal flash and
verifies readback. Network changes are applied through nanoFramework's network
configuration API.

If a write fails, the device attempts to restore both previous snapshots. A
successful rollback reports `persist_failed`; failed rollback reports
`persist_partial`. The candidate remains available for inspection. USB
disconnect or console timeout discards uncommitted changes.

The internal-flash application update is not power-fail atomic because the STM32
sector must be erased. CRC validation rejects incomplete or corrupt records and
the application starts with defaults.

## Related Documents

- [CONFIGURATION_STORAGE.md](CONFIGURATION_STORAGE.md)
- [INTERFACE_COMMAND_MAP_V1.md](INTERFACE_COMMAND_MAP_V1.md)
- [DEVICE_API_V2.md](DEVICE_API_V2.md)

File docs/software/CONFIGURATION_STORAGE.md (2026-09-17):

# Application Configuration Storage

## Purpose

Define the portable Cubley application configuration record and its active
physical backend. Network addressing and DNS remain in the standard
nanoFramework network configuration block.

The application record contains the device hostname, API token, and DiSEqC
positioning calibration.

## Schema 5 Record

The record is exactly 512 bytes. Header integers are little-endian.

| Offset | Size | Field | Description |
|---:|---:|---|---|
| `0x000` | 4 | Magic | ASCII `CCFG` |
| `0x004` | 1 | Schema version | `5` |
| `0x005` | 1 | Flags | Reserved; `0` |
| `0x006` | 2 | Payload length | Used bytes in the payload area |
| `0x008` | 4 | Generation | Monotonic save generation |
| `0x00C` | 4 | CRC32 | CRC32 of used payload bytes |
| `0x010` | 496 | Payload | ASCII `key=value` lines followed by erased padding |

The CRC uses reflected polynomial `0xEDB88320`, initial value `0xFFFFFFFF`, and
final inversion.

The payload contains exactly these keys:

```text
hostname=<configured hostname or empty for automatic>
api_token=<32 to 64 character API token, or empty>
de_lim=<east limit in microdegrees>
dw_lim=<west limit in microdegrees>
de_step=<east step size in microdegrees>
dw_step=<west step size in microdegrees>
d_offset=<signed GoToX offset in microdegrees>
```

Schema 5 is the current application record version. Schema-4 records are
accepted with an empty API token and are rewritten as schema 5 on the next
application-configuration commit. Earlier versions are rejected.

Unknown keys, malformed retained values, invalid field combinations, an
unsupported schema version, and invalid magic, length, or CRC cause the record
to be rejected. The application then uses schema-5 defaults.

## Active Internal Flash Backend

### Capacity Budget

The longest valid application values are a 63-character hostname, a 64-character
API token, `180000000` for each angle limit and step calibration, and
`-180000000` for the signed offset. Together these serialize to 237 payload
bytes, or 253 meaningful bytes including the header. The complete 512-byte slot
remains reserved and written.

The Ethernet HTTPS configuration estimate is:

| Record | Allocated bytes |
|---|---:|
| nanoFramework Ethernet interface | 117 |
| X.509 device-certificate header | 8 |
| Representative P-256 certificate and private-key PEM bundle | 1,067 |
| Cubley application record reservation | 512 |
| **Total** | **1,704 (10.40%)** |
| **Remaining before the Cubley reservation** | **14,680** |

The representative credential uses a maximum-length DNS label in both the
subject common name and subject alternative name, plus an IPv4 alternative
name. Certificate size varies with encoded subject and extensions, so
provisioning must check the actual combined PEM size.

nanoFramework's generic certificate writer uses `__nanoConfig_end__` and is not
aware of the final 512-byte Cubley reservation. The combined size of all
nanoFramework blocks must therefore be limited to 15,872 bytes. With one
117-byte Ethernet record and one 8-byte device-certificate header, the device
certificate payload must not exceed 15,747 bytes. CA bundles, wireless records,
or additional certificates reduce that limit. This Ethernet target does not
use wireless station, wireless AP, or CA-root records in its HTTPS-server
profile.

The STM32 configuration sector spans `0x0800C000` through `0x0800FFFF`. The
final 512 bytes, `0x0800FE00` through `0x0800FFFF`, are reserved for the
application record. Standard nanoFramework configuration data must remain below
`0x0800FE00`.

An update copies the complete 16 KiB sector to RAM, replaces the application
record, erases the sector, writes the complete image, and verifies the record.
This preserves the nanoFramework network configuration block.

Sector erase makes this backend non-atomic across power loss. CRC validation
detects an incomplete record. Writes occur after an explicit USB CDC
configuration commit or an operational `diseqc angle-limits` update.

## Future Backend

The record format is backend-neutral. A future FRAM implementation may store the
same record in generation-selected slots, but FRAM is not initialized or probed
on the current board.

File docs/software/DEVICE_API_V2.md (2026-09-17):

# Device API v2 — JSON Command Envelope And Positioner Jobs

Status: **draft contract**, implemented on the device but not yet exercised on
hardware. REST is the only network interface.

## Why this exists

The previous machine command envelope was
`<decimal id> <console command line>`: the human console grammar used as a wire
format, capped at 64 bytes, with a 16-bit requester-assigned ID as its first
token. Two problems followed from that:

1. The machine API and the operator CLI shared one grammar, so neither could
   change without breaking the other.
2. Long-running positioner movement had no representation. `diseqc goto 12`
   returned `OK` when the *frame was transmitted*, and the only ways to learn
   that motion had ended were a watchdog deadline or the client telling the
   device it had finished (`diseqc complete <motion_id>`) — an inversion of
   who knows what.

v2 separates the two layers. The USB CDC console keeps its Cisco IOS-style
grammar unchanged and remains the primary operator and bring-up interface. The
network transport carries JSON. Both drive the same hardware paths.

## Layering

```
USB CDC  ──  IOS-style CLI  ──┐
                              ├──>  operation  ──>  DiSEqC / LNB hardware
REST     ──  JSON envelope  ──┘
```

Nothing in this document changes the console. An operator types
`diseqc goto 12` at the serial prompt exactly as before.

## Transport

Send commands with `POST /api/v2/commands` over HTTP. The request and response
content type is `application/json`. A command result is returned in the HTTP
response body.

When a token is configured through the USB CDC console, every request MUST
include `Authorization: Bearer <token>`. Missing, malformed, duplicate, and
incorrect authorization headers then return HTTP 401 before endpoint routing or
command execution. An unset token disables authentication.

Read current device state with:

- `GET /api/v2/health`
- `GET /api/v2/state/positioner`
- `GET /api/v2/state/lnb`
- `GET /api/v2/jobs/{job}`

### Payload constraints

The device parses a deliberately small JSON subset. This is a hard contract,
not an implementation detail — it is what makes the parser bounded on a
192 KB-RAM target.

- The payload MUST be a single JSON object.
- Values MUST be string, integer, boolean, or null. **No nested objects, no
  arrays, no floating point.** A fractional or exponent number is rejected.
- At most 12 members; keys at most 24 characters; string values at most 128
  characters.
- The whole payload MUST be at most 256 bytes of ASCII.
- Unknown members are rejected rather than ignored, so a typo fails loudly
  instead of silently doing the wrong thing to a motor.

Byte strings (raw DiSEqC frames) are carried as uppercase hex strings rather
than arrays, e.g. `"frame":"E01038F0"`.

## Command envelope

```json
{"v":2,"id":"01J8ZK4M7Q","op":"positioner.goto","position":12}
```

| Member | Type | Required | Meaning |
|---|---|---|---|
| `v` | int | no (default 2) | Contract version. Only `2` is accepted. |
| `id` | string | **yes** | Requester-assigned idempotency key, 1–32 chars of `A-Za-z0-9._:-`. |
| `op` | string | **yes** | Operation name, 1–40 chars of `a-z0-9._`. |
| … | | | Operation-specific parameters. |

### `id` is an idempotency key, not a correlation tag

HTTP clients can retry after a timeout without knowing whether the device
executed the first request. The requester-assigned `id` prevents a retry of a
non-idempotent operation such as `positioner.step` from executing twice.

### Deduplication

The device remembers the 8 most recent `{id, raw payload, response}`
transactions for **120 seconds**.

- Same `id`, byte-identical payload, within the window → the original response
  is returned verbatim with an added `"replayed":true` member, and the
  command is **not** executed again. `ok` and `code` stay as they originally
  were, so a replay is never mistaken for a fresh execution.
- Same `id`, different payload, within the window → `id_conflict`, nothing
  executes.
- Any `id` older than the window, or evicted by the 8-entry ring → treated as
  new and executed.

The TTL is what makes this predictable: under the v1 slot-count-only scheme,
whether a reused ID replayed or conflicted depended on how many unrelated
commands had happened since. Requesters should still use unique IDs (a ULID or
UUID is ideal, and 32 chars is enough for either).

## Response envelope

Exactly one response object is returned per HTTP request.

```json
{"v":2,"boot_id":"d942c94f-16fd-4d8e-b6d5-44201d3caa4c","id":"01J8ZK4M7Q","ok":true,"code":"accepted","job":7,"ts_ms":41231}
```

| Member | Type | Always | Meaning |
|---|---|---|---|
| `v` | int | yes | Always `2`. |
| `boot_id` | string | yes | Changes on every boot. Job IDs are meaningful only within this boot. |
| `id` | string | yes | Echo of the command `id`, or `"?"` if the envelope was unparseable. |
| `ok` | bool | yes | Whether the command was accepted and completed. |
| `code` | string | yes | Machine-readable outcome, see below. |
| `ts_ms` | int | yes | Device uptime in milliseconds when the response was formed. Monotonic within a boot; **not** wall clock, and it restarts at reboot. |
| `msg` | string | on failure | Short human-readable detail. |
| `job` | int | positioner ops | Job the command started, or the job that blocked it. |
| `data` | object | structured ops | Operation result. Outbound only, so unlike a command payload it may contain nested objects. |
| `lines` | string | bridged ops | Console output, `\n`-separated. See *Bridged operations*. |

### Result codes

| `code` | `ok` | Meaning |
|---|---|---|
| `ok` | true | Completed. Terminal, nothing further happens. |
| `accepted` | true | A job was started. Motion continues after this response. |
| `validation_error` | false | Malformed envelope, unknown member, bad parameter. |
| `unsupported` | false | Unknown `op`, or an op not permitted on this transport. |
| `busy` | false | A positioner job is already running; `job` names it. |
| `hw_fault` | false | Hardware or transmission failure. |
| `id_conflict` | false | `id` reused within the dedup window with a different payload. |
| `not_found` | false | Referenced job is unknown or has been evicted. |

## Positioner job model

A job is created by any command that starts motion, and it is the only thing
that represents "the dish is moving".

### States

| State | Terminal | Meaning |
|---|---|---|
| `running` | no | Frame transmitted; the positioner is presumed moving. |
| `halted` | yes | `positioner.halt` stopped it, or a `stop` was issued at the console. |
| `timeout` | yes | The motion watchdog expired and the device transmitted Halt. |
| `timeout_halt_failed` | yes | The watchdog expired but the Halt transmission failed. **The positioner may still be moving.** |
| `completed` | yes | A client asserted that motion finished and supplied a verification result. |

**There is deliberately no `succeeded` state.** A DiSEqC 1.2 positioner returns
no arrival indication, so the device cannot know the dish reached its target —
it only knows what it transmitted and how much time has passed. `completed`
records a client's result, not motor feedback from the device. A consumer can
report RF verification obtained out of band when it calls
`positioner.complete`.

`timeout` is the normal terminal state for `positioner.drive`, which has no
intrinsic duration, and the fallback for `goto` and `step`.

### Lifecycle

```
positioner.goto/goto_angle/step/drive ──> running ──┬── positioner.halt ────> halted
                                                    ├── watchdog expiry ────> timeout
                                                    │                         timeout_halt_failed
                                                    └── positioner.complete ─> completed
```

Only one job runs at a time. A motion command while a job is `running` fails
with `busy` and names the active job; it does not queue. The device retains the
 4 most recent job records for state queries and release validation.

### Job object

```json
{"job":7,"op":"goto","state":"running","verification":"pending","remaining_ms":83400,"timeout_ms":90000,"detail":""}
```

`remaining_ms` is 0 for terminal states. `detail` carries a failure reason for
`timeout_halt_failed` and is empty otherwise.

`verification` is `pending` while running, `estimated`, `rf_verified`, or
`verification_failed` after client completion, and `none` for other terminal
paths.

## Operations

### Positioner — structured

| `op` | Parameters | Response |
|---|---|---|
| `positioner.goto` | `position` int 0–60 | `accepted` + `job`, or `busy` |
| `positioner.goto_angle` | `direction` `"east"`\|`"west"`, `angle` decimal string from `"0"` through `"180"` with up to six fractional digits | `accepted` + `job`, or `busy` |
| `positioner.step` | `direction` `"east"`\|`"west"`, `count` int 1–128 | `accepted` + `job`, or `busy` |
| `positioner.drive` | `direction` `"east"`\|`"west"` | `accepted` + `job`, or `busy` |
| `positioner.halt` | — | `ok`; terminates the active job as `halted` |
| `positioner.complete` | `job` int, `verification` string | `ok`; terminates that job as `completed` |

`positioner.complete` checks the job id, so a late completion for a superseded
job is rejected rather than ending a newer movement. `verification` accepts:

- `estimated`: adopt a GoToX or calibrated-step pending target with estimated
  confidence.
- `rf_verified`: adopt that pending target with RF-verified confidence. The
  command is rejected if the job has no angular pending target.
- `verification_failed`: invalidate the position estimate.

The device always adopts its own protocol-rounded pending target; the client
cannot inject an arbitrary angle. Stored-position, uncalibrated-step, and
continuous-drive jobs cannot be marked `rf_verified`.

### REST queries

Read-only responses use this envelope and do not require a request ID:

```json
{"v":2,"boot_id":"d942c94f-16fd-4d8e-b6d5-44201d3caa4c","ok":true,"code":"ok","ts_ms":41500,"data":{}}
```

`GET /api/v2/jobs/{job}` returns a retained job object. The device retains the
four most recent jobs; an unknown or evicted ID returns HTTP 404 with
`code=not_found`. `GET /api/v2/state/positioner` returns the active and most
recent terminal jobs plus the current position confidence, estimated angle,
source, and pending target. `GET /api/v2/state/lnb` returns the current LNB
health, communication, fault, register, polarization, and band snapshot.
`GET /api/v2/health` returns liveness and the firmware version.

`angle` is a string because inbound JSON deliberately rejects floating-point
numbers. The operation applies the persisted signed GoToX offset, enforces the
configured direction-specific angular limit, and uses the same DiSEqC rounding
and motion-lock path as console `diseqc goto-angle`.

REST deals with one angle only: the signed USALS angle. The GoToX fixed offset is
an internal calibration factor, so `estimated_angle_deg` and `pending_target_deg`
report the protocol-rounded target converted back to USALS, and neither the
offset nor the offset-adjusted motor angle is published over the network.

### Bridged operations

These ops are accepted on the JSON transport but are still executed by the
legacy console tokenizer, and return console text in `lines` rather than a
structured `data` object:

| `op` | Parameters | Console equivalent |
|---|---|---|
| `lnb.enable` / `lnb.disable` | `channel` | `lnb <ch> enable\|disable` |
| `lnb.polarization` | `channel`, `value` | `lnb <ch> polarization <value>` |
| `lnb.band` | `channel`, `value` | `lnb <ch> band <value>` |
| `diseqc.tx` | `frame` hex string, 1–6 bytes | `diseqc tx <bytes>` |
| `diseqc.preset` | `value` | `diseqc preset <value>` |
| `diseqc.tone` | `value` `"on"`\|`"off"` | `diseqc tone <value>` |

The bridge is a migration stage, not the destination. It exists so the wire
contract could be finalised in one change without rewriting every handler
untested. Moving an op from `lines` to `data` is a **breaking change and
requires a contract version bump** — v2 freezes the shapes above.

Configuration commands remain USB-only and are not exposed by REST.

## Versioning

`v` is the contract version and is checked on every inbound command. Additive,
non-breaking changes (a new op, a new optional response member) keep `v` at 2.
Anything that changes the meaning or shape of an existing member — including
migrating an op from `lines` to `data` — increments it.

## Known gaps

- REST uses TLS 1.3 on TCP port 443. A configured bearer token is required on
  every request; an unset token disables authentication. Restrict network access
  to trusted controllers and protect any configured token as a device credential.
- Clients must validate or pin the provisioned device certificate. Disabling
  certificate validation provides encryption but does not prevent interception.
- `ts_ms` is an uptime tick, not wall clock. There is no RTC.
- REST clients must poll state and job resources; there is no push notification
  interface.

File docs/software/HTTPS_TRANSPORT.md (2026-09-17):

# HTTPS Transport

The REST API listens on TCP port 443 and requires TLS 1.3 with an ECDSA device
certificate. The firmware uses nanoFramework's stock Mbed TLS configuration with
a target override that removes TLS 1.2, DTLS, and their legacy handshake options.

The application uses P-256, SHA-256, and hardware-generated entropy. The stock
native configuration also compiles TLS 1.3, TLS client, RSA, and additional
cipher-suite support even though this REST listener does not request them.

TLS authenticates the server only; the API does not request client certificates.
When an API token is configured, every REST request additionally requires that
bearer token. An unset token disables application authentication. Network ACLs
remain necessary, particularly when authentication is disabled. A client that
disables server-certificate validation can expose a configured token to an
active interceptor.

## Provision A Device Credential

Generate an unencrypted P-256 key and a self-signed certificate for development:

```bash
openssl ecparam -name prime256v1 -genkey -noout -out cubley.key
openssl req -new -x509 -key cubley.key -sha256 -days 3650 \
  -subj "/CN=cubley.local" \
  -addext "subjectAltName=DNS:cubley.local,IP:<device-ip>" \
  -out cubley.crt
cat cubley.crt cubley.key > cubley-device.pem
```

Replace `<device-ip>` before running the command. Keep `cubley.key` and
`cubley-device.pem` secret. An unencrypted key keeps provisioning simple; the
configuration store itself must be protected as secret material.

In the nanoFramework VS Code Device Explorer, select the connected device and
use the device configuration command to update the **X.509 device certificate**.
Upload `cubley-device.pem`, which must contain the certificate followed by its
matching private key. This configuration is separate from managed application
deployment and persists across application updates.

Distribute only `cubley.crt` to API clients. For production, provision a unique
key per device and protect the provisioning workstation and retained backups.

## Provision An API Token

Generate a token and stage it through the USB CDC configuration console:

```text
$ openssl rand -hex 32
cubley-a1b2c3> configure
cubley-a1b2c3(config)# api-token set <generated-token>
cubley-a1b2c3(config*)# commit
```

The token is stored in plaintext in the internal configuration sector and may be
shown in configuration output and command history. Diagnostic logs redact the
token value. When a token is committed, missing or incorrect credentials return
HTTP 401. Use
`api-token clear` followed by `commit` to disable authentication and permit
requests without an authorization header.

## Client Test

```bash
curl --tlsv1.3 --tls-max 1.3 --cacert cubley.crt \
   -H "Authorization: Bearer $CUBLEY_API_TOKEN" \
   "https://<device-ip>/api/v2/health"
```

Use `--insecure` only as a diagnostic to distinguish certificate trust failures
from handshake or application failures.

## Resource Measurements

Measurements are from Debug builds of CUBLEY_F407_0_5:

| Build | nanoCLR flash | 704 KiB region |
|---|---:|---:|
| Current TLS 1.3-only profile | 631,992 bytes | 87.67% |
| Stock TLS 1.2 and TLS 1.3 configuration | 696,696 bytes | 96.64% |
| Experimental TLS 1.2 single-suite profile | 458,848 bytes | 63.65% |

The managed CubleyControl deployment bundle is 190,728 bytes. Current link
inspection confirms that TLS 1.2 record and handshake code is absent while TLS
1.3, RSA, PEM, and the hardware entropy path remain present. The single-suite
result is retained as a measured optimization option, not the active build
configuration.

## Hardware Acceptance

Before release, verify on the board:

1. Provision the combined PEM credential, flash this firmware, and deploy the
   managed application using one deployment workflow.
2. Confirm the TLS 1.3 `curl` command negotiates successfully and a forced TLS
   1.2 connection is rejected.
3. Exercise health, state, command, and job endpoints over repeated connections.
4. Send stalled and malformed handshakes and confirm the two-second socket
   timeout returns the single connection worker to service.
5. Measure native and managed heap headroom and handshake latency during repeated
   connections, then record the results in the bring-up log.

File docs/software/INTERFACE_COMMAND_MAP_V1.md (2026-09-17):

# CubleyControl Interface Map

Status: implemented interfaces as of 2026-09-09

## Purpose

Document the USB CDC command grammar and the separate REST v2 machine interface
implemented by `software/nanoFramework/CubleyControl`. USB commands are
case-insensitive, leading and trailing whitespace is ignored, and repeated spaces
are collapsed. REST uses JSON operations rather than console command text.

## USB CDC Transport

Opening the USB CDC transport displays the product banner followed by `Console
inactive. Press Enter to activate.` Press Enter to acquire the interactive console
lease and display the prompt. There is no `cubley v1` CLI prefix.

Only one USB console may hold the lease at a time. The lease ends when the owner
runs `quit` or `logout`, disconnects, or remains inactive for ten minutes. The
console warns after nine minutes of inactivity. Only operator input refreshes the
lease; periodic `watch` output does not.

In operational mode, empty-line `Ctrl+D` also releases the console. In
configuration mode, `Ctrl+D` retains its existing meaning of leaving configuration
mode when the candidate is clean. `quit` and `logout` release the console from
either mode only when the candidate is clean. Disconnect and inactivity timeout
discard an uncommitted candidate before releasing ownership.

USB `show` commands render labeled, human-readable text. Successful setter and
action commands are silent by default; the changed prompt or subsequent `show`
output provides confirmation.

Failures are framed as:

```text
Fail: <reason>
```

In configuration mode, `debug on` enables the legacy successful-command result
framing for the current USB session. `debug off` restores quiet setters. Failures
remain visible in either mode, and detailed diagnostics are always written to the
firmware debug log.

`help` and `?` display an aligned command-and-description list for the current
mode. `help <command>` displays the corresponding subcommands and usage.

## Command Organization

The USB CDC interface has two responsibilities:

1. Operational control for normal device use.
2. Administrative configuration of network and application settings.

REST provides machine control and read-only state resources. It does not expose
the interactive console mode or configuration commands.

`Ctrl+D` releases a clean operational session. In configuration mode it behaves
like `exit`. Blank lines and lines beginning with `!` are ignored.

### Interface Matrix

| Interface | Control | Read state | Configuration |
|---|---:|---:|---:|
| USB CDC | Console commands | Human-readable `show` commands | Configuration mode |
| REST v2 | `POST /api/v2/commands` | HTTP GET resources | Not exposed |

Configuration mode limits accidental changes; it is not an authentication or
authorization boundary.

### Operational Mode

After console activation, the initial USB prompt is `<hostname>> `. Operational
mode contains normal LNB and DiSEqC control, runtime status, and local diagnostics.
Read-only administrative views remain available at this prompt; entering
configuration mode is required only to mutate configuration.

On connection, the console emits `Cubley Rotation Control v<VERSION>`. Wrapper
builds encode the three-part product version from `AssemblyVersion`, the first
eight Git commit characters, and a `.dirty` suffix when the worktree differs from
that commit, for example `1.0.0+g1a2b3c4d.dirty`. Direct project builds use
`1.0.0+unknown`. `show version` reports the same build version and Git commit.

| Command family | Purpose |
|---|---|
| `show`, `status`, `capabilities`, `version` | Inspect local runtime and build state. |
| `show lnb`, `lnb ...` | Inspect or change LNB outputs. |
| `show diseqc`, `diseqc ...` | Inspect or perform DiSEqC operations. |
| `show network`, `dns lookup` | Inspect network state or run DNS diagnostics. |
| `show running-config`, `show startup-config` | Inspect active or persisted configuration. |
| `watch`, `led`, `pulse` | Run USB or status LED diagnostics. |
| `configure` | Enter configuration mode. |
| `quit`, `logout` | Release the USB console lease. |

### Configuration Mode

`configure` takes a snapshot of the committed network and application
configuration and changes the USB prompt to `<hostname>(config)#`. Configuration
commands update only that candidate until `commit` succeeds. The prompt continues
to use the committed hostname while a different hostname is staged.

#### Device Identity

| Command | Candidate change |
|---|---|
| `hostname <name\|auto>` | Set a DNS-label hostname or derive it from a 24-bit hash of the STM32 unique device ID. |

#### Network Configuration

| Command | Candidate change |
|---|---|
| `network mode <dhcp\|static>` | Select IPv4 address assignment. |
| `network address <ipv4>` | Set the static IPv4 address. |
| `network mask <mask>` | Set the static subnet mask. |
| `network gateway <ipv4>` | Set the static gateway. |
| `network dns auto` | Obtain DNS servers automatically. |
| `network dns static <dns1> [dns2]` | Set one or two static DNS servers. |
| `network defaults` | Stage default DHCP and automatic DNS settings. |

#### Candidate Lifecycle

| Command | Behavior |
|---|---|
| `show storage` | Show the network and application configuration backends and load status. |
| `show candidate-config [network\|application\|diseqc\|all]` | Render the candidate. |
| `show config diff` | Show canonical lines added, removed, or changed relative to the committed configuration. |
| `debug <on\|off>` | Show or suppress successful setter results for the current USB session. |
| `commit` | Validate the complete candidate, persist changed domains, and activate them. |
| `discard` | Replace the candidate with the committed configuration. |
| `load defaults [network\|application\|diseqc\|all]` | Stage defaults without committing them. |
| `exit` | Return to operational mode when clean; `end` and empty-line `Ctrl+D` are equivalent. |

Only one configuration session may own the candidate. `exit` refuses dirty state
to prevent an intentional console action from silently losing work. The prompt is
`<hostname>(config)#` when clean and `<hostname>(config*)#` when the candidate
differs from the running configuration. A dirty exit remains in configuration mode and tells
the operator to use `commit` or `discard`; a second exit never implies discard. A USB
disconnect discards uncommitted changes and releases configuration mode so stale
changes cannot be committed by a later session.

Network and application settings use different persistence backends. `commit`
validates both domains before writing, but power-fail atomic persistence across
both domains is not guaranteed.
A failed multi-domain write retains the candidate and attempts to restore both
previously committed snapshots before anything is activated. A failed write that
is successfully rolled back returns `persist_failed`; `persist_partial` is reserved
for failed recovery.

#### Configuration Aliases

| Canonical form | Accepted aliases |
|---|---|
| `configure` | `config`, `conf`, `configure terminal`, `config terminal`, `conf t` |
| `network` | `net` |
| `network address` | `network addr`, `network ip` |
| `network gateway` | `network gw` |
| `show running-config` | `show run` |
| `show startup-config` | `show start` |
| `show candidate-config` | `show candidate`, `show cand` |
| `show config diff` | `show diff` |
| `show storage` | `show configuration-storage`, `show config-storage` |
| `commit` | `apply` |
| `discard` | `abort` |
| `exit` | `end`, empty-line `Ctrl+D` |

### Textual Configuration

`show running-config` and `show startup-config` produce deterministic,
line-oriented configuration text that can be pasted into configuration mode.
The output uses canonical commands only, includes explicit defaults, and has a
version header. Blank lines and lines beginning with `!` are ignored on input.

```text
! cubley-config v5 startup
hostname cubley-dish-01
network mode static
network address 192.168.1.40
network mask 255.255.255.0
network gateway 192.168.1.1
network dns static 192.168.1.1 1.1.1.1
api-token set 0123456789abcdef0123456789abcdef
diseqc angle-limits 50 50
diseqc step-calibration 0.112658 0.112658
diseqc fixed-offset west 3.38
```

Configuration rendering is generated from the typed configuration objects, not
from either persistence backend's payload. Configured API tokens are emitted in
cleartext, so configuration output is credential-bearing material and must be
protected accordingly.

## Operational Command Reference

## Operator Commands

| Command | Aliases | Behavior |
|---|---|---|
| `help` | `h`, `?` | List commands with brief descriptions. |
| `help <lnb\|show\|diseqc\|network\|dns\|configure>` | `help l` for LNB help | Show aligned command-specific usage. |
| `show status` | `status`, `st` | Show USB CDC and status LED health. |
| `watch [on\|off]` | `w`, values `1\|0`; omitted value means `on` | Enable or disable the periodic serial status line. |
| `show capabilities` | `capabilities`, `caps`, `show caps` | Show the current capability summary. |
| `show version` | `version`, `ver`, `show ver` | Show product, build, Git, interface, and shell identifiers. |
| `led on` | none | Drive the status LED high. |
| `led off` | none | Drive the status LED low. |
| `pulse` | none | Pulse the status LED for 100 ms. |
| `configure` | `config`, `conf`, `configure terminal`, `config terminal`, `conf t` | Enter USB configuration mode. |
| `quit` | `logout`; empty-line `Ctrl+D` in operational mode | Release the interactive console lease. |

## LNB Commands

Logical channels are `a` and `b`. Mutations always require a channel. `l` is an
alias for the `lnb` command family.

### Show

| Command | Behavior |
|---|---|
| `show` | Emit system, both LNB channels, and DiSEqC summary lines. |
| `show lnb` | Emit one summary line for each LNB channel. |
| `show lnb <a\|b>` | Emit one selected channel summary. |
| `show diseqc` | Emit routing preset, tone, carrier settings, transmit-busy state, live motion/position status, and the protocol rounding residual between the requested and estimated angle. |
| `show diseqc detail` | Additionally emit the offset-adjusted commanded angle, step calibration, software limits, GoToX fixed offset, and watchdog timeout. |

Each LNB summary includes enabled state, polarization, band, ISET range, ISW
limit, voltage, tone, low-power mode, external DiSEqC input, and fault registers.

### State Changes

| Command | Aliases | Accepted values |
|---|---|---|
| `lnb <a\|b> enable` | root `l` | none |
| `lnb <a\|b> disable` | root `l` | none |
| `lnb <a\|b> polarization <value>` | `pol`, `p`; root `l` | `vertical\|horizontal`, `v\|h` |
| `lnb <a\|b> band <value>` | `b`; root `l` | `low\|high`, `l\|h` |
| `lnb <a\|b> iset <value>` | root `l` | `default\|normal\|high\|0` or `low\|reduced\|1` |
| `lnb <a\|b> isw <value>` | root `l` | `4a\|4\|default\|high\|0` or `2.5a\|2p5a\|2_5a\|low\|reduced\|1` |

Enabling or disabling a logical channel updates that channel's native LNB output
state. Assignment commands require a value; all reads begin with `show`.

## Network And Application Configuration

Network addressing is persisted by nanoFramework. Hostname and DiSEqC
positioning settings are written to the portable schema-5 application record.
All are changed only through USB configuration mode.

| Command | Behavior |
|---|---|
| `show network` | Show active link, MAC, IPv4, and DNS state. |
| `show running-config [network\|application\|diseqc\|all]` | Show active non-default configuration. |
| `show startup-config [network\|application\|diseqc\|all]` | Show persisted configuration. |

Configuration backend and load diagnostics are available separately as
`show storage` from USB configuration mode.

The public operational grammar does not use `get` or `set`. Configuration
mutations are accepted only after entering configuration mode.

Configuration mode accepts persistent `diseqc angle-limits <east> <west>`,
`diseqc step-calibration <east> <west>`, and
`diseqc fixed-offset <east|west> <degrees>` values. `commit` writes them to the
portable application record. A fixed offset is added to the signed USALS motor
angle before direction-specific limit checking and GoToX encoding. For example,
`fixed-offset west 3.38` changes a requested `36.6` degrees east to an effective
`33.22` degrees east, encoded as `33.2` degrees.

## DiSEqC Commands

| Command | Accepted values and behavior |
|---|---|
| `diseqc goto <position>` | Go to TM-2300 stored position `0..60`. Position `0` is the motor reference; this is not an angle command. |
| `diseqc goto-angle <east\|west> <degrees>` | Send positioner command `0x6E` for an explicit motor angle. Decimal degrees are rounded to the nearest tenth, with half-step ties rounded upward, then encoded with the DiSEqC GoToX fractional lookup. A direction-specific software limit must first be configured. |
| `diseqc reference` | Send `0x6B 0x00` to move to the motor's reference position. |
| `diseqc store <position>` | Store the current physical position in motor slot `1..60` with command `0x6A`. |
| `diseqc recalculate` | Send the basic `0x6F 0x00` Set/Recalculate Positions command. For the TM-2300 receiver workflow this re-synchronizes the selected stored position and shifts the others; the DiSEqC specification defines parameter `0x00` as manufacturer-specific, so verify this behavior on the installed motor before relying on it. |
| `diseqc motor-limit <east\|west\|off>` | Send motor-internal limit command `0x66`, `0x67`, or `0x63`. East or west records the motor's current physical position as that limit. This does not configure Cubley's angular safety limits. |
| `diseqc angle-limits <east_degrees> <west_degrees>` | Persist positive, direction-specific limits in the protocol range through 180 degrees and apply them after verified storage. Rejected during motion. The operator must choose values strictly inside the motor's physically adjusted hardware stops. |
| `diseqc angle-limits status` | Show whether angular motion is armed and both direction limits. |
| `diseqc angle-limits off` | Persist disabled angular movement and apply it after verified storage. Rejected during motion. |
| `diseqc step-calibration <east_deg_per_step> <west_deg_per_step>` | Temporarily set direction-specific step sizes with up to six decimal places. Operational changes are RAM-only; values committed in USB configuration mode are loaded again after reboot. |
| `diseqc step-calibration status` | Show step calibration and position-estimate state. |
| `diseqc step-calibration off` | Disable step calibration. |
| `diseqc step <east\|west> <steps>` | Move `1..128` steps. |
| `diseqc drive <east\|west>` | Start continuous movement. |
| `diseqc stop` | Transmit the positioner halt command. |
| `diseqc complete <motion_id>` | Release the matching motion lock after external completion detection. |
| `diseqc preset <off\|direct\|aa\|ab\|ba\|bb>` | Select the routing prefix applied to positioner commands. |
| `diseqc preset status` | Show the selected routing preset. |
| `diseqc timeout <5..300>` | Set the motion watchdog auto-stop timeout, in seconds. Rejected while a motion is in progress. |
| `diseqc timeout status` | Show the configured motion watchdog timeout, in seconds. |
| `diseqc tx <framing> <address> <command> [data_byte ...]` | Transmit 3 to 6 hexadecimal bytes. |
| `diseqc tone on [frequency_hz] [duty_percent]` | Start the carrier; defaults to 22000 Hz and 50%. Frequency range is 1000..100000 Hz and duty range is 1..99%. |
| `diseqc tone off` | Stop the carrier. |
| `diseqc tone status` | Show carrier state and settings. |
| `diseqc listen <on\|off>` | Enable or disable the channel-A LNBH26 external DiSEqC input; boolean aliases are accepted. |

The selected preset prefixes all first-class positioner commands, including
`goto`, `goto-angle`, `reference`, `store`, `recalculate`, `motor-limit`, `step`,
`drive`, and `stop`.
Raw `diseqc tx` frames are transmitted unchanged. Successful `goto`, `goto-angle`,
`step`, and `drive` commands hold a motion lock that rejects further movement and
raw frames. Step commands use a step-derived deadline capped by the configured
motion watchdog timeout; goto and drive use the configured motion watchdog timeout directly. The timeout defaults to
90 seconds and is adjustable from 5 to 300 seconds with `diseqc timeout <seconds>`.
First-class motor movement temporarily selects horizontal polarization so the
positioner receives 18 V for the full motion. The previous polarization is
restored when the motion is completed, halted, or timed out.
When the timeout elapses, the firmware transmits Halt automatically and marks the
motion complete with `completion=timeout`. `diseqc stop` is always accepted and
clears the lock after transmitting Halt. An external completion command must
include the current motion ID so a delayed signal cannot release a newer movement.

`goto-angle` uses the DiSEqC 1.2 five-byte form `E0 31 6E xx xx`.
The two data bytes contain an east (`0xE`) or west (`0xD`) direction nibble and
a whole-degree magnitude followed by the standard fractional-tenth code lookup
`0,2,3,5,6,8,A,B,D,E`. For example, east `36.6` encodes as `E2 4A`.
Input is strict unsigned decimal text with at most six fractional digits; signs,
exponent notation, and locale decimal separators are rejected because direction
is a separate argument. The local estimate remains in microdegrees so calibrated
steps can retain finer resolution than the GoToX command.

Angular software limits start disabled after boot unless persistent values were
explicitly committed. This fail-closed behavior requires the operator or future station
orchestrator to confirm the motor's adjustable hardware stops before arming a
bounded session. A configured software value is not evidence that the physical
hardware limit was measured correctly.

Motion command results and DiSEqC state/events record `command_mode`,
`requested_angle_deg`, `direction`, `movement_voltage_v`,
`position_confidence`, `estimated_angle_deg`, `position_source`,
`pending_target_deg`, `step_calibration_configured`, `east_step_deg`, and
`west_step_deg`. Every reported angle is a signed USALS angle; the fixed GoToX
offset is an internal calibration factor and is never reported outside the USB
console. The retained state also records
`angle_limits_configured`, `east_limit_deg`, and `west_limit_deg`. A successful
GoToX transmission records a pending target without changing the previous
estimate. Matching external completion adopts the protocol-rounded target,
converted back to USALS by removing the fixed offset, as
`position_confidence=estimated`. A calibrated step similarly adopts its pending
target on external completion. Stored-position movement, reference movement,
continuous drive, Halt, uncalibrated step completion, and raw positioner commands
leave the angular estimate `unknown`; watchdog expiry sets `verification_failed`.
No command-only transition is reported as `rf_verified`.

The reported `direction` is the requested USALS direction. Stored-position and
reference moves report `none` because the motor determines the path. When the
fixed GoToX offset is large enough to flip the sign of the effective angle, the
motor travels in the opposite direction; that offset-adjusted view is available
only on the USB console as "Commanded angle (after GoToX offset)" in
`show diseqc detail`, alongside the step calibration, software limits, and the
fixed offset itself.

GoToX carries 0.1 degree resolution in the offset-adjusted motor domain, so an
angular target whose offset-adjusted angle is not an exact tenth of a degree is
rounded before transmission. Removing the offset again leaves the reported USALS
estimate up to 0.05 degrees away from the entered angle. USB `show diseqc`
reports that residual as "Protocol rounding (estimate - request)"; for example a
requested east 36.6 degrees reported as 36.58 degrees shows `-0.02 deg`. The
residual is expected quantization, not a tracking error.

## Canonical Command IDs

Dotted IDs such as `system.version.get` and `diseqc.lnb.set.band` remain available
to internal contracts but are not executable USB command forms. External
commands use the operational grammar documented above.

## REST v2 Interface

REST is the sole network interface. It listens for TLS 1.3 on TCP port 443 after
the device has a usable IPv4 address. When configured, every request requires
the `Authorization: Bearer <token>` credential; an unset token disables
authentication. Client certificates are not used.

| Request | Purpose |
|---|---|
| `POST /api/v2/commands` | Execute one JSON operation and return its result. |
| `GET /api/v2/health` | Read liveness and firmware version. |
| `GET /api/v2/state/positioner` | Read active/last jobs and position estimate. |
| `GET /api/v2/state/lnb` | Read LNB health, faults, registers, polarization, and band. |
| `GET /api/v2/jobs/{job}` | Read one of the four retained positioner jobs. |

Supported operation families are:

- `positioner.goto`, `positioner.goto_angle`, `positioner.step`,
  `positioner.drive`, `positioner.halt`, and `positioner.complete`.
- `lnb.enable`, `lnb.disable`, `lnb.polarization`, and `lnb.band`.
- `diseqc.tx`, `diseqc.preset`, and `diseqc.tone`.

REST does not expose console help, watch output, LED diagnostics, DNS lookup, or
configuration mode. Clients poll job and state GET resources for progress and
recovery. See [DEVICE_API_V2.md](DEVICE_API_V2.md) for envelope, idempotency,
validation, and job semantics.

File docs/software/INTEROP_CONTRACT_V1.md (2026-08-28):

# Interop Contract (CubleyNative v1)

## Purpose

Define the frozen nanoFramework InternalCall dispatch map for `CubleyNative`.
The runtime dispatch index is the PE `MethodDef` index, not managed source order.

## Scope

- Managed assembly: `CubleyNative`
- Managed declarations: `software/nanoFramework/CubleyNative.Interop/CubleyInteropNative.cs`
- Canonical native table: `firmware/targets-local/CUBLEY_F407_0_5/nanoCLR/cubley_interop.cpp`
- Native CLR wrappers: `firmware/targets-local/CUBLEY_F407_0_5/nanoCLR/*_interop.cpp`
- Runtime export: `g_CLR_AssemblyNative_CubleyNative`

The corresponding community-target tree is generated during the firmware build and is not an edit source.

## Identity

- Assembly name: `CubleyNative`
- Managed and native assembly version: `1.0.0.0`
- Native methods checksum: `0x0A4353F9`
- Frozen slot count: 26 (`0..25`)
- Current slot count: 30 (`0..29`)

## PE Ordering

The nanoFramework MetadataProcessor orders methods by declaring type name
(ordinal alphabetical order), then by declaration order within each type.
The native `method_lookup[]` table must follow that emitted order exactly.

The current type order is:

1. `DiagMailbox`
2. `Fram24C128`
3. `LNBH26`
4. `LNBH26Registers`
5. `LNBH26Tweaks`
6. `UsbCdcConsole`
7. `ZPersistentConfiguration`
8. `ZZDiseqcTransmitter`

## Canonical Slot Map
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

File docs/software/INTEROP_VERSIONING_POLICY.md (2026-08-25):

# Interop Versioning Policy (v1.x)

## Purpose

Define compatibility and review rules for the `CubleyNative` managed/native contract.

## Policy Scope

- Managed declarations in `software/nanoFramework/CubleyNative.Interop/CubleyInteropNative.cs`
- Canonical native lookup/export in `firmware/targets-local/CUBLEY_F407_0_5/nanoCLR/cubley_interop.cpp`
- Native CLR wrappers in `firmware/targets-local/CUBLEY_F407_0_5/nanoCLR/*_interop.cpp`
- Guards in `software/nanoFramework/toolchain/interop-guard.sh` and `interop-checksum.sh`
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

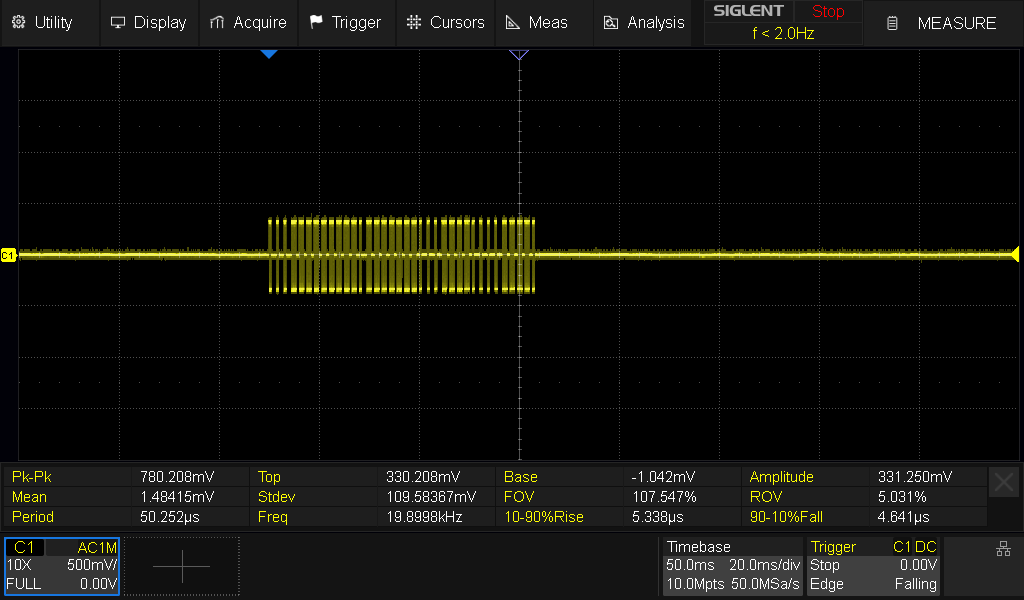
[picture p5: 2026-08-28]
docs/debug/artifacts/rf-interface-2026-08-27/20260828-scope-j8-diseqc-hardware-timing-fixed.png

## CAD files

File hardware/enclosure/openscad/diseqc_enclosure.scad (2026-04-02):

// DiSEqC controller printable enclosure (base + lid)
// Units: mm

$fn = 64;

// -----------------------------------------------------------------------------
// Board and case envelope
// -----------------------------------------------------------------------------
pcb_w = 90.0;   // X (left-right)
pcb_l = 100.0;  // Y (front-back)
pcb_t = 1.6;

xy_clearance = 1.0;   // free space around PCB edges
wall = 2.4;
floor_t = 2.4;
top_clearance = 18.0; // free height above PCB top

// PCB support ledges (no mounting-hole assumptions)
ledge_depth = 1.6;
ledge_drop = 0.8;     // ledge is slightly below PCB bottom
standoff_h = 5.0;     // PCB bottom Z above base floor

// Lid behavior
lid_t = 2.4;
lid_lip_h = 5.0;
lid_gap = 0.3;        // fit clearance between lid lip and base

// Output mode: "base", "lid", or "preview"
mode = "preview";

// -----------------------------------------------------------------------------
// Derived dimensions
// -----------------------------------------------------------------------------
inner_w = pcb_w + 2 * xy_clearance;
inner_l = pcb_l + 2 * xy_clearance;
inner_h = standoff_h + pcb_t + top_clearance;

outer_w = inner_w + 2 * wall;
outer_l = inner_l + 2 * wall;
base_h = floor_t + inner_h;

// Useful references in case coordinates
board_x0 = wall + xy_clearance;
board_y0 = wall + xy_clearance;
pcb_bottom_z = floor_t + standoff_h;

// -----------------------------------------------------------------------------
// Connector cutouts
// Coordinates are PCB-space values translated from the KiCad board:
// board outline 50..140 (X), 50..150 (Y), so y_from_board_bottom = y - 50.
// Tune these after a quick fit print.
// -----------------------------------------------------------------------------

// J1 Barrel Jack (left wall)
J1_enable = true;
J1_y = 25.125;
J1_z = pcb_bottom_z + 2.8;
J1_h = 8.2;
J1_w = 12.0;

// J4 USB-C (left wall)
J4_enable = true;
J4_y = 79.665;
J4_z = pcb_bottom_z + 1.6;
J4_h = 4.2;
J4_w = 11.0;

// J8 RJ45 (left wall)
J8_enable = true;
J8_y = 61.19;
J8_z = pcb_bottom_z + 6.4;
J8_h = 14.5;
J8_w = 16.8;

// J6/J7 SMA pair (right wall) as one slot for tolerance
J67_enable = true;
J67_y = 76.26;
J67_z = pcb_bottom_z + 5.8;
J67_h = 18.0;
J67_w = 30.0;

// -----------------------------------------------------------------------------
// Geometry helpers
// -----------------------------------------------------------------------------
module rounded_box(size_xyz, r) {
    x = size_xyz[0];
    y = size_xyz[1];
    z = size_xyz[2];
    hull() {
        for (sx = [r, x - r]) {
            for (sy = [r, y - r]) {
                translate([sx, sy, 0]) cylinder(h = z, r = r);
            }
        }
    }
}

module left_cutout(y_center, z_center, w_y, h_z) {
    translate([-0.1, wall + y_center - w_y / 2, z_center - h_z / 2])
        cube([wall + 0.2, w_y, h_z]);
}

module right_cutout(y_center, z_center, w_y, h_z) {
    translate([outer_w - wall - 0.1, wall + y_center - w_y / 2, z_center - h_z / 2])
        cube([wall + 0.2, w_y, h_z]);
}

module pcb_ledges() {
    z0 = pcb_bottom_z - ledge_drop;

    // Long ledges, split around side cutout zones.
    translate([wall, wall, z0]) cube([ledge_depth, inner_l, ledge_drop + pcb_t + 0.6]);
    translate([outer_w - wall - ledge_depth, wall, z0]) cube([ledge_depth, inner_l, ledge_drop + pcb_t + 0.6]);

    // End stops to keep board from sliding in Y.
    translate([wall + ledge_depth, wall, z0]) cube([inner_w - 2 * ledge_depth, ledge_depth, ledge_drop + pcb_t + 0.6]);
    translate([wall + ledge_depth, outer_l - wall - ledge_depth, z0]) cube([inner_w - 2 * ledge_depth, ledge_depth, ledge_drop + pcb_t + 0.6]);
}

module base_shell() {
    difference() {
        rounded_box([outer_w, outer_l, base_h], 3.0);
        translate([wall, wall, floor_t]) cube([inner_w, inner_l, inner_h + 0.2]);

        if (J1_enable) left_cutout(J1_y, J1_z, J1_w, J1_h);
        if (J4_enable) left_cutout(J4_y, J4_z, J4_w, J4_h);
        if (J8_enable) left_cutout(J8_y, J8_z, J8_w, J8_h);
        if (J67_enable) right_cutout(J67_y, J67_z, J67_w, J67_h);
    }

    pcb_ledges();
}

module lid_shell() {
    // Plate
    difference() {
        rounded_box([outer_w, outer_l, lid_t], 3.0);

        // Optional lightweighting pocket.
        translate([wall + 8, wall + 8, -0.1])
            rounded_box([inner_w - 16, inner_l - 16, lid_t - 0.9], 2.0);
    }

    // Locating lip
    translate([0, 0, -lid_lip_h])
    difference() {
        rounded_box([outer_w, outer_l, lid_lip_h], 2.2);
        translate([wall - lid_gap, wall - lid_gap, -0.1])
            rounded_box([inner_w + 2 * lid_gap, inner_l + 2 * lid_gap, lid_lip_h + 0.2], 1.8);
    }
}

module assembly_preview() {
    color([0.86, 0.86, 0.9]) base_shell();

    // Simple PCB proxy for visual checks.
    color([0.0, 0.4, 0.1, 0.5])
        translate([board_x0, board_y0, pcb_bottom_z])
            cube([pcb_w, pcb_l, pcb_t]);

    color([0.8, 0.82, 0.84, 0.6])
        translate([0, 0, base_h + 8])
            lid_shell();
}

if (mode == "base") {
    base_shell();
} else if (mode == "lid") {
    lid_shell();
} else {
    assembly_preview();
}

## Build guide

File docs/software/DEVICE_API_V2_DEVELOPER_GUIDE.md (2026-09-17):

# Cubley Device REST API v2 Developer Guide

Status: **draft and subject to change**. The API is implemented but has not yet
been fully exercised on hardware. The canonical contract is
[DEVICE_API_V2.md](DEVICE_API_V2.md).

## Transport

- Base URL: `https://<device-ip>`
- Endpoint: `POST /api/v2/commands`
- Read endpoints: `/api/v2/health`, `/api/v2/state/positioner`,
  `/api/v2/state/lnb`, and `/api/v2/jobs/{job}`
- Content type: `application/json`
- TLS 1.3 encryption is required. Clients must trust or pin the provisioned
  device certificate; client certificates are not requested.
- When a token is configured, every request requires
  `Authorization: Bearer <token>` and missing or incorrect credentials return
  HTTP 401 before routing. An unset token disables authentication.
- HTTP status-code mappings are not yet contractual. Clients should parse the
  JSON response envelope.

## Request Envelope

```json
{
  "v": 2,
  "id": "unique-request-id",
  "op": "positioner.goto",
  "position": 12
}
```

- `v`: Contract version; currently `2`.
- `id`: Required idempotency key, 1-32 characters matching `A-Za-z0-9._:-`.
- `op`: Required operation name.
- Remaining fields depend on the operation.

Generate a new `id` for each logical command. Retrying the exact same payload
with the same ID within 120 seconds does not execute it twice.

## Payload Restrictions

Requests must:

- Be one JSON object, no larger than 256 ASCII bytes.
- Contain at most 12 members.
- Use keys no longer than 24 characters.
- Use string values no longer than 128 characters.
- Contain only strings, integers, booleans, or `null`.
- Not contain arrays, nested objects, floating-point, or exponent numbers.
- Not contain unknown members.

Raw DiSEqC frames use uppercase hex strings, for example `"E01038F0"`.

## Operations

| Operation | Parameters |
|---|---|
| `positioner.goto` | `position`: integer 0-60; position 0 is the motor reference |
| `positioner.goto_angle` | `direction`: `"east"` or `"west"`; `angle`: decimal string from `"0"` through `"180"`, with up to six fractional digits |
| `positioner.step` | `direction`: `"east"` or `"west"`; `count`: integer 1-128 |
| `positioner.drive` | `direction`: `"east"` or `"west"` |
| `positioner.halt` | None |
| `positioner.complete` | `job`: integer; `verification`: `estimated`, `rf_verified`, or `verification_failed` |
| `lnb.enable` | `channel` |
| `lnb.disable` | `channel` |
| `lnb.polarization` | `channel`, `value` |
| `lnb.band` | `channel`, `value` |
| `diseqc.tx` | `frame`: uppercase hex, 1-6 bytes |
| `diseqc.preset` | `value` |
| `diseqc.tone` | `value`: `"on"` or `"off"` |

The accepted values for bridged LNB fields are not fully frozen in the draft.
Coordinate with the firmware team before depending on them.

Configuration operations are available only through the USB console, not REST.

## Response Envelope

```json
{
  "v": 2,
  "boot_id": "d942c94f-16fd-4d8e-b6d5-44201d3caa4c",
  "id": "unique-request-id",
  "ok": true,
  "code": "accepted",
  "job": 7,
  "ts_ms": 41231
}
```

Always present:

- `v`: Contract version.
- `boot_id`: Per-boot identity; treat job IDs from another boot as stale.
- `id`: Request ID, or `"?"` if parsing failed.
- `ok`: Whether the command was accepted or completed.
- `code`: Machine-readable result.
- `ts_ms`: Device uptime, not wall-clock time.

Optional:

- `msg`: Failure detail.
- `job`: Started or blocking positioner job.
- `data`: Structured result.
- `lines`: Newline-separated output from legacy bridged operations.
- `replayed`: The response came from the idempotency cache.

Result codes are `ok`, `accepted`, `validation_error`, `unsupported`, `busy`,
`hw_fault`, `id_conflict`, and `not_found`.

## Positioner Jobs

Motion operations return `accepted` with a job ID and continue asynchronously.
Only one motion job may run at a time; another motion request returns `busy`.

Job states:

- `running`
- `halted`
- `timeout`
- `timeout_halt_failed`
- `completed`

There is no `succeeded` state because DiSEqC does not report arrival. A
controller should detect completion externally, such as through signal lock,
then call:

```json
{
  "v": 2,
  "id": "complete-7",
  "op": "positioner.complete",
  "job": 7,
  "verification": "rf_verified"
}
```

`rf_verified` promotes the device's offset-adjusted and protocol-rounded pending
target to `position_confidence=rf_verified`; the client does not supply an
angle. Use `estimated` when motion stopped without independent verification, or
`verification_failed` when RF evidence disproves arrival. Stored-position,
uncalibrated-step, and continuous-drive jobs have no angular pending target and
cannot be marked `rf_verified`.

A watchdog eventually halts incomplete motion.

## State Queries

All read responses include `v`, `boot_id`, `ok`, `code`, `ts_ms`, and `data`.
Poll `GET /api/v2/jobs/{job}` after a motion command. A missing or evicted job
returns HTTP 404 and `code=not_found`. Use `GET /api/v2/state/positioner` to
recover the active job and position confidence after reconnecting, and
`GET /api/v2/state/lnb` for current LNB health and fault state.

`GET /api/v2/health` is the lightweight liveness endpoint. A changed `boot_id`
means cached job IDs and uptime values belong to an earlier boot.

## Polling And Recovery

The device has no push notification interface. After a motion command returns
`accepted`, poll `GET /api/v2/jobs/{job}` until the job becomes terminal. Use a
bounded interval appropriate to the controller; polling faster than the motor can
change state provides no benefit.

After a timeout or network reconnect:

1. Read `GET /api/v2/health` and compare `boot_id` with the previous response.
2. Read `GET /api/v2/state/positioner` to recover the active job, most recent
  terminal job, and position estimate.
3. If the boot ID is unchanged and the job is retained, resume polling
  `GET /api/v2/jobs/{job}`.
4. Read `GET /api/v2/state/lnb` when the workflow depends on LNB power, fault,
  polarization, or band state.

A changed `boot_id` invalidates prior job IDs and uptime comparisons. An HTTP 404
with `code=not_found` means the job is unknown or has left the four-entry retention
ring; recover from the positioner snapshot rather than resubmitting motion
blindly.

## Example

```bash
curl --cacert cubley.crt -X POST "https://<device-ip>/api/v2/commands" \
  -H "Authorization: Bearer $CUBLEY_API_TOKEN" \
  -H "Content-Type: application/json" \
  --data '{"v":2,"id":"goto-12-001","op":"positioner.goto","position":12}'
```

## Calibrated GoToX Sequence

The following sequence enables LNB output A, references the motor, and then
moves to the Cheltenham Astra 2 GoToX angle. It requires `jq`, persisted GoToX
offset and angular limits, and a fresh request ID for every logical command.
Only complete each job after observing that the motor has physically stopped.

```bash
BASE_URL="https://<device-ip>/api/v2/commands"
export CURL_CA_BUNDLE="cubley.crt"
AUTH_HEADER="Authorization: Bearer $CUBLEY_API_TOKEN"
run_id="cal-$(date +%s)"

curl -fsS "$BASE_URL" \
  -H "$AUTH_HEADER" \
  -H 'Content-Type: application/json' \
  --data "{\"v\":2,\"id\":\"$run_id-lnb\",\"op\":\"lnb.enable\",\"channel\":\"a\"}"

reference_response=$(curl -fsS "$BASE_URL" \
  -H "$AUTH_HEADER" \
  -H 'Content-Type: application/json' \
  --data "{\"v\":2,\"id\":\"$run_id-ref\",\"op\":\"positioner.goto\",\"position\":0}")
printf '%s\n' "$reference_response" | jq .
reference_job=$(printf '%s\n' "$reference_response" |
  jq -er 'select(.ok and .code == "accepted") | .job')

# Wait for the motor to stop at reference before completing this job.
curl -fsS "$BASE_URL" \
  -H "$AUTH_HEADER" \
  -H 'Content-Type: application/json' \
  --data "{\"v\":2,\"id\":\"$run_id-ref-complete\",\"op\":\"positioner.complete\",\"job\":$reference_job,\"verification\":\"estimated\"}"

goto_response=$(curl -fsS "$BASE_URL" \
  -H "$AUTH_HEADER" \
  -H 'Content-Type: application/json' \
  --data "{\"v\":2,\"id\":\"$run_id-astra2\",\"op\":\"positioner.goto_angle\",\"direction\":\"east\",\"angle\":\"36.6\"}")
printf '%s\n' "$goto_response" | jq .
goto_job=$(printf '%s\n' "$goto_response" |
  jq -er 'select(.ok and .code == "accepted") | .job')

# Wait for physical cessation and verify the known Astra 2 signal first.
curl -fsS "$BASE_URL" \
  -H "$AUTH_HEADER" \
  -H 'Content-Type: application/json' \
  --data "{\"v\":2,\"id\":\"$run_id-astra2-complete\",\"op\":\"positioner.complete\",\"job\":$goto_job,\"verification\":\"rf_verified\"}"
```

Do not complete a job if arrival is uncertain. Use `positioner.halt` instead; a
Halt or watchdog timeout deliberately prevents the pending target from becoming
an estimated position.

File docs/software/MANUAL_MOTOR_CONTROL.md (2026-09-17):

# Manual Motor Control Guide

## Purpose

Provide direct rotor movement commands for calibration and fine tuning.

## Scope

This guide covers DiSEqC manual movement commands exposed by the native/C# integration layer.

## DiSEqC 1.2 Manual Commands

### Available Commands

| Command | DiSEqC Bytes | Description |
|---|---|---|
| **StepEast** | `E0 31 68 XX` | Move East by XX steps |
| **StepWest** | `E0 31 69 XX` | Move West by XX steps |
| **DriveEast** | `E0 31 68 00` | Continuous East (until Halt) |
| **DriveWest** | `E0 31 69 00` | Continuous West (until Halt) |
| **Halt** | `E0 31 60` | Stop movement |

### Step Size
- Typically **1 step ≈ 1 degree** (rotor dependent)
- Maximum: 128 steps per command
- For larger movements, use multiple step commands or GotoAngle

## 💻 C# API Reference

### Low-Level API (DiSEqC.Native)

```csharp
using DiSEqC_Control.Native;

// Step movements (incremental)
DiSEqC.StepEast(1);      // Move 1 step East (~1°)
DiSEqC.StepEast(5);      // Move 5 steps East (~5°)
DiSEqC.StepWest(1);      // Move 1 step West (~1°)
DiSEqC.StepWest(10);     // Move 10 steps West (~10°)

// Continuous movements (hold)
DiSEqC.DriveEast();      // Start moving East
Thread.Sleep(2000);      // Move for 2 seconds
DiSEqC.Halt();           // Stop

DiSEqC.DriveWest();      // Start moving West
Thread.Sleep(1000);      // Move for 1 second
DiSEqC.Halt();           // Stop

// Check status
bool busy = DiSEqC.IsBusy();
```

### High-Level API (RotorManager)

```csharp
using DiSEqC_Control.Manager;

var rotor = new RotorManager();

// Single step movements
rotor.StepEast();        // Move 1 step East (default)
rotor.StepWest();        // Move 1 step West (default)
rotor.StepEast(5);       // Move 5 steps East
rotor.StepWest(3);       // Move 3 steps West

// Continuous movements
rotor.DriveEast();       // Start continuous East
Thread.Sleep(2000);
rotor.Halt();            // Stop

rotor.DriveWest();       // Start continuous West
Thread.Sleep(1500);
rotor.Halt();            // Stop
```

## 🎯 Usage Examples

### Example 1: Fine-Tuning Position

```csharp
using DiSEqC_Control.Manager;

var rotor = new RotorManager();

// Go to approximate position
rotor.GotoAngle(45.0f);
while (rotor.IsBusy()) Thread.Sleep(100);

// Fine-tune manually
rotor.StepEast();  // Nudge slightly East
Thread.Sleep(500);

rotor.StepWest(2); // Adjust slightly West
Thread.Sleep(500);
```

### Example 2: Button-Based Manual Control

```csharp
// Button press handlers
void OnEastButtonPressed()
{
    if (!rotor.IsBusy())
    {
        rotor.StepEast(1);  // Single step
    }
}

void OnWestButtonPressed()
{
    if (!rotor.IsBusy())
    {
        rotor.StepWest(1);  // Single step
    }
}

// Long press for continuous
void OnEastButtonHeld()
{
    rotor.DriveEast();  // Start continuous
}

void OnButtonReleased()
{
    rotor.Halt();  // Stop on release
}
```

### Example 3: REST v2 Manual Control

Network automation uses `POST /api/v2/commands`. Give every logical action a
unique ID; retry the exact same body and ID after an ambiguous HTTP failure.

```bash
base="https://<device-ip>"

curl --cacert cubley.crt -fsS "$base/api/v2/commands" \
    -H "Authorization: Bearer $CUBLEY_API_TOKEN" \
  -H 'Content-Type: application/json' \
  --data '{"v":2,"id":"step-east-001","op":"positioner.step","direction":"east","count":1}'

curl --cacert cubley.crt -fsS "$base/api/v2/commands" \
    -H "Authorization: Bearer $CUBLEY_API_TOKEN" \
  -H 'Content-Type: application/json' \
  --data '{"v":2,"id":"drive-west-001","op":"positioner.drive","direction":"west"}'

curl --cacert cubley.crt -fsS "$base/api/v2/commands" \
    -H "Authorization: Bearer $CUBLEY_API_TOKEN" \
  -H 'Content-Type: application/json' \
  --data '{"v":2,"id":"halt-001","op":"positioner.halt"}'
```

Motion responses include a job ID. Poll `GET /api/v2/jobs/{job}` for terminal
state, and use `GET /api/v2/state/positioner` to recover after reconnecting. See
[DEVICE_API_V2.md](DEVICE_API_V2.md) for the complete contract.

### Example 4: Automatic Scanning

```csharp
// Scan for satellite signal by stepping
async Task ScanForSignal()
{
    const int STEPS_PER_SCAN = 1;
    const int MAX_STEPS = 30;  // Scan ±30 degrees

    // Start from current position
    for (int i = 0; i < MAX_STEPS; i++)
    {
        rotor.StepEast(STEPS_PER_SCAN);
        await Task.Delay(1000);  // Wait for movement + signal check

        float signalQuality = ReadSignalQuality();  // Your signal reading

        if (signalQuality > 80.0f)
        {
            Console.WriteLine($"Signal found! Quality: {signalQuality}%");
            return;
        }
    }

    // Scan back West
    for (int i = 0; i < MAX_STEPS * 2; i++)
    {
        rotor.StepWest(STEPS_PER_SCAN);
        await Task.Delay(1000);

        float signalQuality = ReadSignalQuality();

        if (signalQuality > 80.0f)
        {
            Console.WriteLine($"Signal found! Quality: {signalQuality}%");
            return;
        }
    }

    Console.WriteLine("Signal not found in scan range");
}
```

## ⚠️ Important Notes

### Safety Considerations

1. **Check Busy State**
   ```csharp
   if (!rotor.IsBusy())
   {
       rotor.StepEast();  // Only if not already moving
   }
   ```

2. **Always Halt Continuous Movement**
   ```csharp
   rotor.DriveEast();
   // ALWAYS call Halt() to stop!
   Thread.Sleep(2000);
   rotor.Halt();  // ✅ Don't forget!
   ```

3. **Respect Motor Limits**
   - Most rotors have software/hardware limits
   - Don't drive past ±80 degrees
   - The rotor will typically auto-halt at limits

4. **Don't Spam Commands**
   ```csharp
   rotor.StepEast();
   while (rotor.IsBusy()) Thread.Sleep(50);  // Wait for completion
   rotor.StepEast();  // Now safe to send next command
   ```

### Step Size Calibration

Different rotors have different step sizes:
- **Most DiSEqC 1.2 rotors**: 1 step ≈ 1 degree
- **High-precision rotors**: 1 step ≈ 0.5 degree
- **Check your rotor manual** for exact step size

### Command Timing

- Each step command takes ~67ms to transmit
- Rotor movement time varies (typically 50-200ms per step)
- Add delays between commands for rotor to complete movement

## 🧪 Testing Manual Control

### Test 1: Single Step

```csharp
rotor.GotoAngle(0);  // Go to reference position
Thread.Sleep(5000);  // Wait to complete

rotor.StepEast();    // Step East once
Thread.Sleep(2000);  // Wait

// Verify position changed (signal meter, compass, etc.)
```

### Test 2: Multiple Steps

```csharp
for (int i = 0; i < 5; i++)
{
    rotor.StepEast();
    Thread.Sleep(1000);  // Wait between steps
}

// Should have moved ~5 degrees East
```

### Test 3: Continuous Drive

```csharp
Console.WriteLine("Starting continuous East...");
rotor.DriveEast();

Thread.Sleep(3000);  // Drive for 3 seconds

Console.WriteLine("Stopping...");
rotor.Halt();

// Rotor should have moved continuously for 3 seconds
```

## 🎮 UI Control Example

```html
<!-- Simple web UI -->
<div class="rotor-control">
    <button onclick="stepWest()">◀ Step West</button>
    <button onclick="halt()">■ HALT</button>
    <button onclick="stepEast()">Step East ▶</button>

    <br>

    <button onmousedown="driveWest()" onmouseup="halt()">◀◀ Hold West</button>
    <button onmousedown="driveEast()" onmouseup="halt()">Hold East ▶▶</button>
</div>

<script>
let commandSequence = 0;
const apiToken = '<configured-api-token>';

function sendCommand(op, parameters = {}) {
    commandSequence += 1;
    return fetch('/api/v2/commands', {
        method: 'POST',
        headers: {
            'Authorization': `Bearer ${apiToken}`,
            'Content-Type': 'application/json'
        },
        body: JSON.stringify({
            v: 2,
            id: `manual-${Date.now()}-${commandSequence}`,
            op,
            ...parameters
        })
    }).then(response => response.json());
}

function stepEast() {
    return sendCommand('positioner.step', {direction: 'east', count: 1});
}

function stepWest() {
    return sendCommand('positioner.step', {direction: 'west', count: 1});
}

function driveEast() {
    return sendCommand('positioner.drive', {direction: 'east'});
}

function driveWest() {
    return sendCommand('positioner.drive', {direction: 'west'});
}

function halt() {
    return sendCommand('positioner.halt');
}
</script>
```

---

**You can now manually control your satellite dish rotor with precision!** 🎯

For automatic positioning, use `GotoAngle()`. For fine-tuning and manual control, use the step/drive functions above.

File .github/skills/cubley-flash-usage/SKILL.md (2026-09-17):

---
name: cubley-flash-usage
description: "Generate current CUBLEY_F407_0_5 logical flash-layout and physical erase-sector usage tables from built nanoBooter, nanoCLR, managed deployment, and configuration estimates. Use when asked for flash blocks, capacities, fill level, free flash, memory map, sector usage, firmware size, or deployment occupancy. Keywords: flash usage, flash table, erase sectors, nanoCLR size, deployment size, configuration fill."
---

# Cubley Flash Usage

## Purpose

Produce the two canonical Markdown flash tables for the current build:

1. Logical regions: nanoBooter, configuration, nanoCLR, and managed deployment.
2. STM32F407 physical erase sectors 0 through 11.

## Command

From the repository root, run:

```bash
python3 tools/report_flash_usage.py
```

If an actual combined device certificate/private-key PEM is available, use its
size instead of the representative 1,067-byte P-256 credential:

```bash
python3 tools/report_flash_usage.py --device-certificate path/to/device.pem
```

For a measured configuration-sector occupancy, override the estimate:

```bash
python3 tools/report_flash_usage.py --config-used <bytes>
```

## Preconditions

Build both firmware and managed artifacts first. The script requires:

- `firmware/nf-interpreter/build/nanoBooter.bin`
- `firmware/nf-interpreter/build/nanoCLR.bin`
- `software/nanoFramework/build/CubleyControl/latest.deploy.bin`

## Interpretation

- Artifact sizes are occupied extents, not counts of non-erased bytes read from hardware.
- Configuration is estimated unless `--config-used` is supplied.
- The default estimate includes the Ethernet record, X.509 header,
  representative P-256 PEM bundle, and complete 512-byte Cubley reservation.
- The script validates the expected target linker and block-storage geometry and
  stops if the source layout no longer matches its STM32F407 assumptions.
- Report script errors rather than reconstructing tables manually.

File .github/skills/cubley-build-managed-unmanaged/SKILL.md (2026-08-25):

---
name: cubley-build-managed-unmanaged
description: "Use when running end-to-end managed + native build/deploy for CUBLEY_F407_0_5, including interop validation, firmware rebuild, payload deployment, and diagnostics verification. Keywords: build-CubleyControl.sh, build-flash-cubley.sh, interop-checksum, st-flash, latest.deploy.bin, diagnostics mailbox."
---

# Cubley Managed+Native Build/Deploy Workflow

## Purpose

Run a deterministic workflow for this repo when both managed and native code may have changed, and verify the board is actually running the expected mailbox-enabled image.

## Primary Targets

- software/nanoFramework/toolchain/build-CubleyControl.sh
- firmware/build-flash-cubley.sh
- software/nanoFramework/toolchain/interop-checksum.sh
- software/nanoFramework/tests/swd_read_bringup_status.sh
- docs/debug/BRINGUP_TEST_LOG.md

## When To Use

- Any change touching `Cubley.Interop` interop declarations.
- Any change touching `firmware/targets-local/CUBLEY_F407_0_5/` native or startup code.
- Any change touching managed startup/probe flow (`StartupProbe`, `Program`, config boot path).
- When board behavior does not match code expectations and stale firmware is suspected.

## Preconditions

1. ST-Link connected and visible.
2. Board power stable.
3. Build host has required tools (`msbuild`, `arm-none-eabi-*`, `st-flash`, `openocd`, `gdb-multiarch`).
4. Run commands from the repository root unless a step says otherwise.

## Canonical Full Flow

1. Build managed assemblies and deterministic deploy bundle:
   - `cd software/nanoFramework`
   - `./toolchain/build-CubleyControl.sh build --project CubleyControl/CubleyControl.nfproj --configuration Debug`

2. Validate interop checksum alignment:
   - `./toolchain/interop-checksum.sh --check --assembly CubleyNative --pe build/CubleyControl/CubleyNative.pe`

3. If checksum mismatch is reported, fix then re-check:
   - `./toolchain/interop-checksum.sh --fix --assembly CubleyNative --pe build/CubleyControl/CubleyNative.pe`
   - `./toolchain/interop-checksum.sh --check --assembly CubleyNative --pe build/CubleyControl/CubleyNative.pe`

4. Rebuild the canonical firmware target from the repository root:
   - `cd ../..`
   - `./firmware/build-flash-cubley.sh build`

5. Flash the Debug firmware layout after verifying addresses in the generated maps:
   - `./firmware/build-flash-cubley.sh flash --reset`

6. Deploy the managed payload over the wire protocol:
   - `cd software/nanoFramework`
   - `./toolchain/deploy-CubleyControl.sh --reset`

7. Verify diagnostics mailbox:
   - `./tests/swd_read_bringup_status.sh`

8. Append factual run result:
   - `./toolchain/bringup_log_append.sh --result PASS|FAIL|INFO --conclusion "..." --commands "..." --artifact "..."`

## Quick Managed-Only Refresh (No Native Rebuild)

Use only when native binary compatibility is known unchanged.

1. `./toolchain/build-CubleyControl.sh build --project CubleyControl/CubleyControl.nfproj --configuration Debug`
2. `./toolchain/deploy-CubleyControl.sh --reset`
3. `./tests/swd_read_bringup_status.sh`

If startup stalls or mailbox values are unexpected, switch to Canonical Full Flow.

## Verification Criteria

1. `build-CubleyControl.sh build` creates a validated deterministic bundle.
2. `firmware/build-flash-cubley.sh build` produces `nanoBooter.bin` and `nanoCLR.bin` successfully.
3. `st-flash` verifies booter/CLR/payload writes.
4. Mailbox script reports sane values with `0xD5` status magic for active diagnostic channels.

## Known Failure Signatures

1. Interop checksum mismatch:
   - Symptom: check step reports mismatch between AssemblyInfo and native table.
   - Action: run `interop-checksum.sh --fix` and re-check.

2. CLR resolve pointer values in mailbox (magic not `0xD5`):
   - Symptom: current/error words look like flash pointers (e.g., `0x080c....`).
   - Action: decode missing assembly and ensure bundle includes required `.pe` dependency.

## Guardrails

- Never flash payload into booter/CLR regions.
- Do not skip checksum validation after interop signature/table changes.
- Treat `latest.deploy.bin` as authoritative payload artifact for SWD deployment.
- Record every significant run in `docs/debug/BRINGUP_TEST_LOG.md`.

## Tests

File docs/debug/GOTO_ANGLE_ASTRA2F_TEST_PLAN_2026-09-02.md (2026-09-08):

# GoTo-Angle Astra 2F Repeatability Test Plan

Date: 2026-09-02
DUT: Cubley `cubley-a02663` with TM-2300 M3 positioner
Target: Astra 2F / 28.2 degrees east orbital slot

## Purpose

Prove that `diseqc goto-angle` can return the dish to the same 28.2 degrees east
RF peak after approaching from both lower and higher motor angles. This is a
bounded Gate 0 test, not an autonomous scan and not proof of motor feedback.

The test uses a stable horizontal, low-band anchor near 11.224 GHz RF
(approximately 1.474 GHz IF with a 9.75 GHz LO). Confirm the carrier assignment
before the run. Without independently verified service or catalogue metadata,
the RF result proves pointing at the 28.2 degrees east Astra cluster rather than
identifying the transmitting spacecraft uniquely as Astra 2F.

## Safety Gates

1. Confirm the motor's physical east/west stops, clear travel path, cable slack,
   dish fasteners, and mechanical zero/reference before applying movement.
2. Keep an immediately available `diseqc stop` command throughout the test.
3. Use conservative volatile software limits strictly inside the physical stops.
   Limits start disabled after every Cubley boot and must never be copied from
   this document without checking the installation.
4. Test only the target and two nearby flank positions. Do not use continuous
   drive or raw `diseqc tx`.
5. Stop on an unexpected direction, LNB fault, obstruction, cable tension,
   watchdog expiry, MQTT/console loss, or uncertain motion state.
6. User commands are issued over USB CDC. That console is not accessible from
   the development container.

## Values Required Before Arming Motion

Record these values before sending `diseqc angle-limits`:

| Item | Value |
| --- | --- |
| Station latitude, north positive | |
| Station longitude, east positive | |
| Independently calculated target direction | |
| Independently calculated target magnitude | |
| Cubley target after tenth-degree GoToX quantization (`A`) | |
| Lower signed-motor-angle flank (`L`) | |
| Higher signed-motor-angle flank (`H`) | |
| Command-coordinate mapping to observed physical east/west movement | |
| East software limit | |
| West software limit | |
| Motion watchdog | |
| RF receiver path and configuration | |
| Anchor centre frequency | |

Calculate the initial target using the host helper, substituting the measured
station coordinates:

```bash
cd /workspaces/diseqc_cntrl
PYTHONPATH=software/transponder-mapper/src /usr/bin/python3 -c \
  'from satmap.central.usals import calculate_motor_target; print(calculate_motor_target(LATITUDE, LONGITUDE, 28.2))'
```

Cross-check the result against one independent USALS implementation or a
known-good receiver before motion. Use a signed motor coordinate only in the
worksheet: east is positive and west is negative. Convert each command to
Cubley's explicit direction plus unsigned magnitude. In this plan, increasing
and decreasing refer only to that signed command coordinate. Record the observed
physical dish direction separately during the first screening legs; do not infer
it from the words `L`, `H`, east, or west.

Start with flank positions one motor degree on either side of `A`:

$$L=A-1.0^\circ$$

$$H=A+1.0^\circ$$

Both flanks must remain inside the verified software and hardware limits. A
one-degree offset should produce a clear anchor reduction for a typical Ku dish.
If it does not, increase the offset only after stopping and reassessing clearance;
do not exceed two degrees during this Gate 0 test.

## Measurement Metric

Use one receiver path and unchanged gain, bandwidth, detector, averaging, and
LNB state for the entire run. Prefer the rooftop bladeRF/Cubley path; the indoor
Siglent may provide a separate corroborating series.

For each dwell, record integrated anchor power relative to adjacent noise:

$$C/N_{adj}=P_{carrier}-P_{adjacent\ noise}$$

This relative metric is less sensitive than raw power to slow gain drift. Do not
change SDR gain or analyser reference settings after collecting the baseline.

## Preflight

1. Start an MQTT event/state capture if available, while retaining USB CDC for
   the interactive safety command.
2. Set and verify the anchor LNB state:

   ```text
   lnb a enable
   lnb a polarization horizontal
   lnb a band low
   show lnb a
   ```

3. Tune the receiver to the anchor and allow the LNB/receiver to warm and settle.
4. With the dish already peaked at the known anchor, collect ten stationary
   $C/N_{adj}$ measurements at fixed intervals. Record mean $\mu_0$ and standard
   deviation $\sigma_0$. Define the measurable-change threshold
   $T=\max(1.0\ \mathrm{dB},3\sigma_0)$ before moving.
5. Confirm fail-closed behavior after boot: `diseqc angle-limits status` must show
   disabled until deliberately armed. Do not issue a movement merely to test
   rejection if the current physical position is uncertain.
6. Configure checked limits and a watchdog no longer than 30 seconds for these
   one-to-two-degree legs, then read them back. Reduce it further only if prior
   measured travel time provides adequate margin; do not use the 90-second
   default for this bounded test.

   ```text
   diseqc angle-limits <east_limit_deg> <west_limit_deg>
   diseqc timeout <seconds>
   diseqc angle-limits status
   diseqc timeout status
   show diseqc
   ```

7. Verify the reported LNB voltage is appropriate for horizontal polarization
   and record it. The movement voltage affects travel time, not destination.

## Motion Handling For Every Leg

1. Send one `diseqc goto-angle <east|west> <degrees>` command and record its
   motion ID, requested angle, encoded angle, direction, and movement voltage.
2. Confirm the initial physical movement is in the expected direction. Send
   `diseqc stop` immediately if it is not.
3. Wait until the motor has physically stopped, then allow a fixed mechanical
   settle interval of at least five seconds.
4. Send `diseqc complete <motion_id>` only after observing the physical stop.
   This command sends no Halt; it only releases the matching firmware motion
   lock and records `completion=external`, `position_confidence=estimated`. This
   is an open-loop estimate at the encoded target, not stop sensing or RF
   verification. If
   physical cessation is uncertain, use `diseqc stop` instead and abort the run.
5. Run `show diseqc` and confirm the lock is idle, completion is `external`, and
   the requested/encoded target matches the worksheet.
6. Reapply the LNB state, then verify it before measuring RF:

   ```text
   lnb a polarization horizontal
   lnb a band low
   show lnb a
   show diseqc
   ```

7. Reject the dwell if completion is `timeout`, confidence is
   `verification_failed`, the encoded target differs from the worksheet, or an
   LNB/motion fault occurred.

If the watchdog expires, firmware attempts Halt, clears the motion lock, and
sets `position_confidence=verification_failed`. Do not send another movement.
Confirm physical cessation, issue `diseqc stop` if any doubt remains, inspect
`show diseqc` and `show lnb a`, disable angular limits, and end the test. If Halt
fails or motion continues, disable LNB/motor power using the station's emergency
power procedure.

## Test Sequence

Run one screening cycle first:

1. `A -> L`: confirm the physical direction matches the recorded mapping and the
   anchor decreases by at least $T$.
2. `L -> A`: settle, reapply LNB state, and measure the anchor.
3. `A -> H`: confirm the physical direction reverses and the anchor decreases by
   at least $T$.
4. `H -> A`: settle, reapply LNB state, and measure the anchor.

Stop here if either return fails. If both returns pass, run two more cycles for
three arrivals at `A` from each direction. Alternate the order to limit drift:

```text
Cycle 1: A -> L -> A -> H -> A
Cycle 2: A -> H -> A -> L -> A
Cycle 3: A -> L -> A -> H -> A
```

Do not count the initial already-peaked baseline as a directional arrival.

## Results

| Cycle | Approach to A | Motion ID | Requested A | Encoded A | Completion | Settle (s) | $C/N_{adj}$ (dB) | Result/notes |
| ---: | --- | ---: | ---: | ---: | --- | ---: | ---: | --- |
| 1 | from L / increasing angle | | | | | | | |
| 1 | from H / decreasing angle | | | | | | | |
| 2 | from H / decreasing angle | | | | | | | |
| 2 | from L / increasing angle | | | | | | | |
| 3 | from L / increasing angle | | | | | | | |
| 3 | from H / decreasing angle | | | | | | | |

Record separately:

| Metric | Result |
| --- | ---: |
| Baseline mean $\mu_0$ | |
| Baseline standard deviation $\sigma_0$ | |
| Measurable-change threshold $T$ | |
| Mean after increasing-angle approach | |
| Mean after decreasing-angle approach | |
| Difference between directional means | |
| Worst return below baseline mean | |
| Unexpected direction/fault/watchdog count | |

## Pass Criteria

All conditions must pass:

1. Six of six directional arrivals reacquire the same anchor carrier.
2. Every arrival encodes exactly the same target `A`; no arrival completes by
   watchdog timeout or reports `verification_failed`.
3. Every returned $C/N_{adj}$ is no more than $T$ below the stationary baseline
   mean.
4. The two directional mean values differ by no more than
   $T$.
5. Both flanks are at least $T$ below the stationary target baseline, proving
   that the sequence crossed the local RF peak rather than remaining inside a
   flat measurement region.
6. There are no unexpected-direction events, LNB faults, motion faults,
   obstructions, cable concerns, or emergency stops.

If only the directional-mean criterion fails, record the result as backlash or
approach-direction dependence, not as a reliable pass. Retain separate preferred
angles by approach direction until a later lobe fit determines a compensation.

## Shutdown

1. Return to `A` only if the last movement state is known and the test remains
   inside all safety gates; otherwise send `diseqc stop` and leave position
   confidence unknown.
2. Disable angular movement for the remainder of the session:

   ```text
   diseqc angle-limits off
   diseqc angle-limits status
   show diseqc
   ```

3. Apply the station's normal LNB power policy.
4. Preserve receiver traces, command/event capture, calculated target, firmware
   build identity, and this completed worksheet.
5. Append one factual PASS or FAIL entry to `docs/debug/BRINGUP_TEST_LOG.md` after
   reviewing the artifacts. Do not log a timeout as successful arrival.

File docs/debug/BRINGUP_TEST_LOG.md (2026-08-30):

# DiSEqC nanoFramework Bring-up Test Log

This file tracks factual checkpoints, commands, and outcomes for the STM32F407 bring-up.

## Device under test
- Target: M0DMF_CUBLEY_F407
- MCU: STM32F407
- Bootloader: nanoBooter present

## 2026-04-07 Timeline

### 1) Firmware and flash layout validation
- Confirmed linker/storage intent:
  - nanoBooter: 0x08000000-0x08004000
  - nanoCLR: 0x08004000-0x080C0000
  - Deployment: 0x080C0000-0x08100000
- Rebuilt native firmware with minimal profile.
- Enabled config block for minimal profile in build script.

### 2) Deployment image validation
- Verified deployment flash at 0x080C0000 can contain NFMRK2 bytes, but current GDB evidence indicates the CLR is not promoting that wrapped image into candidate assembly descriptors on this target.
- Rebuilt BlinkBringup managed project and retained the raw PE output as the next deployment candidate.
- Current preferred managed artifact for bring-up retest:
  - tests/BlinkBringup/bin/Release/BlinkBringup.pe

### 3) Runtime/GDB findings
- nanoCLR wire protocol is alive (NFPKTV1 observed).
- Current symbol map distinction:
  - 0x08001e00 is nanoBooter Reset_Handler.
  - CLR startup symbols are in higher flash addresses in nanoCLR.elf.
- Therefore, breakpoints in CLR loader code will not hit until booter hands off to CLR.

### 4) Current observed behavior (important)
- nanoff --devicedetails reports:
  - Native assemblies present.
  - Managed Assemblies: none.
- Interpretation:
  - Not a total boot failure.
  - Managed deployment is still not being accepted/loaded at runtime.

## Next-step checkpoint script (GDB)
Use this order to prove booter-to-CLR handoff before assembly loader tracing.

1. Reset and clear breakpoints.
2. Break at booter handoff points:
   - 0x0802664 (load CLR reset vector)
   - 0x080267a (branch to CLR reset)
3. Break at CLR Reset_Handler in nanoCLR.elf:
   - 0x08035b0c
4. Continue and inspect:
   - memory at 0x08004000 (vector table)
   - register r0 at booter branch

## Operating rule for future tests
For each run, append one short entry with:
- Command(s) run
- Artifact used
- Address breakpoints used
- Baseline status (yes/no)
- Pass/fail result
- One-line conclusion

Each entry must include `Command(s)` and `Artifact` fields so the run can be replayed from the log. Use `Artifact: none` only when no artifact applies.
New entries should also include explicit baseline status, with `yes` as the default for cubley-base runs and `no` for any deviation documented against [PHASE_A_BASELINE.md](./PHASE_A_BASELINE.md).

## Quick logging helper
Use the helper to append timestamped entries consistently:

- `./toolchain/bringup_log_append.sh --result PASS|FAIL|INFO --commands "..." --artifact "..." --conclusion "one-line conclusion"`
  The helper emits the baseline line automatically; pass `--baseline no` only for explicit non-baseline runs.

Recommended full form for debug sessions:

- `./toolchain/bringup_log_append.sh --result FAIL --commands "gdb: b *0x08002664; b *0x0800267a; b *0x08035b0c" --artifact "tests/BlinkBringup/bin/Release/BlinkBringup.pe" --breakpoints "0x08002664, 0x0800267a, 0x08035b0c" --conclusion "Booter handoff reached; CLR reset hit; deployment candidate descriptors still not promoted"`

### 2026-04-07 14:32:55 UTC [INFO]
- Git rev: 2f9d1c3
- Command(s): nanoff erase + deploy + devicedetails
- Artifact: tests/BlinkBringup/bin/Release/BlinkBringup.pe
- Conclusion: Allemblies contains BlinkBringup, 1.0.0.0 but nothing else

### 2026-04-07 16:16:48 UTC [PASS]
- Git rev: 2f9d1c3
- Command(s): nanoff --nanodevice --serialport /dev/ttyUSB0 --baud 115200 --deploy --image tests/BlinkBringup/bin/Release/BlinkBringup.pe --address 0x080C0000 --reset
- Artifact: tests/BlinkBringup/bin/Release/BlinkBringup.pe
- Conclusion: Managed GPIO writes confirmed working after fixing board grounding issue; UART3 nanoFramework connection is now stable.

### 2026-04-07 19:57:40 UTC [PASS]
- Git rev: 2f9d1c3
- Command(s): rebuild minimal firmware after fixing nanoBooter startup; flash nanoBooter.bin to 0x08000000; flash nanoCLR.bin to 0x08004000; nanoff deploy tests/BlinkBringup/bin/Release/BlinkBringup_startfirst_with_events.bin; GDB startup-chain and IL/GPIO probes
- Artifact: tests/BlinkBringup/bin/Release/BlinkBringup_startfirst_with_events.bin
- Breakpoints: ResolveAll 0x0802d598, PrepareForExecution 0x0802e864, NewThread 0x080320f0, Execute_IL 0x08009788, Native GPIO write 0x0801f5cc
- Conclusion: Root causes were incomplete managed deployment, incorrect host flashing of nanoCLR at 0x08010000 instead of 0x08004000, and invalid nanoBooter startup sequencing using osDelay() before the RTOS scheduler was started. After fixing nanoBooter_main.c, flashing at linker-defined addresses, and deploying the with-events managed bundle, startup progressed through ResolveAll and PrepareForExecution, NewThread was hit twice, Execute_IL was hit 44 times, and native GPIO write was observed.

## 2026-04-08 Session Update

### 2026-04-08 11:58:48 UTC [FAIL]
- Git rev: 2f9d1c3
- Command(s):
  - Rebuilt both firmware profiles from scratch and verified fresh artifact times:
    - `./toolchain/build-native.sh bringup-smoke`
    - `./toolchain/build-native.sh minimal`
  - Rebuilt managed test app clean:
    - removed `tests/BlinkBringup/bin/Release` and `tests/BlinkBringup/obj/Release`
    - `./toolchain/compile-blink-test.sh`
  - Flashed firmware correctly:
    - `st-flash write build/nanoBooter.bin 0x08000000`
    - `st-flash write build/nanoCLR.bin 0x08004000`
  - Deployed managed images over SWD (UART intermittently unavailable in this session):
    - `st-flash write tests/BlinkBringup/bin/Release/BlinkBringup.pe 0x080C0000`
    - `st-flash write tests/BlinkBringup/bin/Release/BlinkBringup.bin 0x080C0000`
    - `st-flash write .debug/BlinkBringup_with_threading.bin 0x080C0000`
  - Runtime probes via OpenOCD + gdb-multiarch with one-shot breakpoint scripts in `.debug/`.
- Artifacts:
  - `tests/BlinkBringup/bin/Release/BlinkBringup.pe` (fresh NFMRK1 single assembly)
  - `tests/BlinkBringup/bin/Release/BlinkBringup.bin` (fresh bundled image)
  - `.debug/BlinkBringup_with_threading.bin` (BlinkBringup.bin + System.Threading.pe)
- Breakpoints/probes and outcomes:
  - `CLR_RT_Assembly::CreateInstance` at 0x0801435c: HIT, record pointer `r0=0x080C0000` (deployment image is discovered).
  - `CLR_RT_TypeSystem::ResolveAll` at 0x0802D598: HIT.
  - After `ResolveAll` return at 0x08019DAC: `r0=0xA3000000` (negative HRESULT), repeatable across all tested deployment images.
  - `CLR_RT_TypeSystem::PrepareForExecution` 0x0802E864: NOT HIT.
  - `CLR_RT_ExecutionEngine::NewThread` 0x080320F0: NOT HIT.
  - `CLR_RT_Thread::Execute_IL` 0x08009788: NOT HIT.
  - Native GPIO write (`Library_sys_dev_gpio_native...::NativeWrite`) 0x0801F5CC: NOT HIT.
- Conclusion:
  - Managed deployment region and assembly discovery are working, but managed startup aborts in type resolution (`ResolveAll` returns `0xA3000000`) before any managed thread or IL executes.
  - Therefore LED not toggling is a startup/dependency-resolution failure in CLR bring-up, not a PA2 GPIO runtime write-path failure.
  - Additional note: `/dev/ttyUSB0` was not consistently available during this run, so validation was completed via SWD/GDB only.

### Immediate follow-up objective
- Build a deterministic managed deployment pack step in tooling (single known-good bundle containing all required assemblies) and gate deployment on a post-pack verification check before flashing.

---

## Resumption Plan (pending UART restoration)

Authored: 2026-04-08. Status: PENDING — blocked on `/dev/ttyUSB0` unavailability (Windows host usbipd issue).

The following steps are ordered by dependency. Steps 1 and 2 require UART. Steps 3–5 can proceed via SWD only once the root cause in step 2 is established.

### Step 0 — Restore UART access
- Fix usbipd attachment on Windows host so `/dev/ttyUSB0` appears reliably in the WSL/Linux environment.
- Verify with: `ls -l /dev/ttyUSB0 && stty -F /dev/ttyUSB0 115200`
- Goal: enable `nanoff` wire-protocol commands (`--devicedetails`, `--deploy`) to work again.
- No firmware or code changes needed for this step.

### Step 1 — Identify the exact unresolved assembly reference
This is the root cause that must be established before any toolchain fix.

**Why `ResolveAll` fails is still unknown.** The deployed bundle appears to contain BlinkBringup + System.Device.Gpio + nanoFramework.Runtime.Events, and System.Threading is present in CLR flash — yet `ResolveAll` returns `0xA3000000`.

Approach A — Use `nanoff --devicedetails` with UART restored:
```
nanoff --nanodevice --serialport /dev/ttyUSB0 --baud 115200 --devicedetails
```
This reports which managed assemblies the CLR has accepted and which are missing. Compare the "needs assembly" messages printed to UART with what is deployed.

Approach B — Read assembly names from UART output at startup:
```
screen /dev/ttyUSB0 115200
# power-cycle board; observe CLR startup prints:
#   Assembly: <name> (<version>)
#   needs assembly '<name>' (<version>)   <- these are the missing references
```
The `"needs assembly"` lines identify the exact unresolved dependency by name and version.

Approach C (SWD fallback, no UART) — Breakpoint on the `CLR_Debug::Printf` call that emits `"needs assembly"`:
- Locate the call site in `CLR_Startup` that prints the needs-assembly message (search nf-interpreter source for `"needs assembly"`).
- Place a breakpoint there; read `r1` (format) and `r2`/`r3`/stack args (name and version strings) when hit.
- Current probe template: `.debug/gdb_probe_*.cmd` one-shot pattern.

Expected deliverable: a text note recording exactly which assembly name+version `ResolveAll` cannot close.

### Step 2 — Build a corrected deployment bundle
Once the missing reference is identified:
1. Locate or build the correct `.pe` file for the missing assembly from the NuGet package cache or from a `nanoff`-extracted device package.
2. Concatenate all required PEs into a single bundle:
   ```
   cat BlinkBringup.pe System.Device.Gpio.pe nanoFramework.Runtime.Events.pe <missing>.pe > BlinkBringup_complete.bin
   ```
3. Verify bundle integrity: all NFMRK records present, no truncation.
   ```
   python3 toolchain/inspect_deploy_bundle.py BlinkBringup_complete.bin
   ```
   (script to be written if not already present; reads 4-byte NFMRK2 headers and prints each PE name/version/size)
4. Flash bundle: `st-flash write BlinkBringup_complete.bin 0x080C0000`
5. Run the after-ResolveAll probe to confirm `r0` is no longer `0xA3000000`:
   ```
   nohup timeout 15s gdb-multiarch -batch -x .debug/gdb_probe_after_resolveall.cmd build/nanoCLR.elf \
     > .debug/gdb_probe_after_resolveall.out 2>&1
   grep -E 'AFTER_RESOLVEALL|r0' .debug/gdb_probe_after_resolveall.out
   ```

### Step 3 — Re-run the full startup-chain probe sequence
Once `ResolveAll` passes (returns `S_OK = 0x00000000`), repeat all five probes in order:

| Probe | Address | Expected result |
|---|---|---|
| `CLR_RT_Assembly::CreateInstance` | 0x0801435C | HIT, `r0=0x080C0000` |
| `CLR_RT_TypeSystem::ResolveAll` | 0x0802D598 | HIT |
| After `ResolveAll` return | 0x08019DAC | `r0=0x00000000` (S_OK) |
| `CLR_RT_TypeSystem::PrepareForExecution` | 0x0802E864 | HIT |
| `CLR_RT_ExecutionEngine::NewThread` | 0x080320F0 | HIT (≥1 time) |
| `CLR_RT_Thread::Execute_IL` | 0x08009788 | HIT (≥1 time) |
| Native GPIO write | 0x0801F5CC | HIT (≥1 time) |

All seven must pass before bring-up is considered complete for managed code on this target.

### Step 4 — Harden the toolchain pack step
Implement `toolchain/pack-and-validate.sh`:
- Accepts a list of PE files as arguments.
- Verifies each file has the NFMRK header (`hexdump -C` check on first 4 bytes = `4E 46 4D 32`).
- Concatenates them in the correct order.
- Verifies total size is ≤ 0x40000 (260 KB, deployment region limit).
- Writes output to a timestamped `.deploy.bin` file and a stable `latest.deploy.bin` symlink.
- Exits non-zero if any check fails.

Rationale: the 2026-04-08 failure was caused by the toolchain emitting a bundle that silently lacked a required assembly. A pack-time validator catches this before flashing.

### Step 5 — Lock toolchain versions
Record in `toolchain/versions.lock`:
- nanoFramework NuGet package versions used by BlinkBringup (from `packages.config`)
- nanoCLR firmware git ref (or tag) that matches those package versions
- `nanoff` version used for deployment

This file should be committed and checked on each build to prevent version drift between the CLR native assemblies and the managed packages.

---

### 2026-04-08 13:50:04 UTC [INFO]
- Git rev: 4391075
- Command(s): toolchain/pack-and-validate.sh + toolchain/inspect_deploy_bundle.py + toolchain/run-startup-gate.sh
- Artifact: tests/BlinkBringup/bin/Release/BlinkBringup_complete-20260408T134739Z.deploy.bin
- Conclusion: Deterministic deployment bundle tooling is in place and generated successfully; live UART/SWD validation remains blocked in this shell by Linux device permissions (ttyUSB0 root:root 0600 and OpenOCD LIBUSB_ERROR_ACCESS).

### 2026-04-08 14:36:38 UTC [PASS]
- Git rev: 4391075
- Command(s): pack-and-validate NFMRK1 + st-flash deploy + sequential startup gate
- Artifact: tests/BlinkBringup/bin/Release/BlinkBringup_full_stack-20260408T143420Z.deploy.bin
- Breakpoints: 0x0801435c, 0x0802d598, 0x08019dac, 0x0802e864, 0x080320f0, 0x08009788, 0x0801f5cc
- Conclusion: ResolveAll now returns S_OK (0x0) and managed startup progresses through PrepareForExecution, NewThread, Execute_IL, and native GPIO write with full dependency-complete NFMRK1 bundle.

### 2026-04-08 15:16:04 UTC [INFO]
- Git rev: 4391075
- Command(s): `./toolchain/run-startup-gate.sh`; `nanoff --nanodevice --serialport /dev/ttyUSB0 --devicedetails`
- Artifact: `.debug/gdb_startup_gate.out`
- Probe summary:
  - `GATE_CREATEINSTANCE=1`
  - `GATE_RESOLVEALL=1`
  - `GATE_AFTER_RESOLVEALL=1`
  - `GATE_RESOLVEALL_HR=0x0`
  - `GATE_PREPAREFOREXEC=1`
  - `GATE_NEWTHREAD=1`
  - `GATE_EXECUTE_IL=1`
  - `GATE_NATIVEWRITE=1`
- Conclusion: Managed startup path remains healthy and reproducible via SWD probes, but UART-side `nanoff --devicedetails` still fails with `Error E2001` in this session, so device enumeration/transport remains the remaining blocker for serial bring-up validation.

### 2026-04-08 15:19:16 UTC [INFO]
- Git rev: 4391075
- Command(s): `nanoff --listports`; `nanoff --nanodevice --listdevices`; baud sweep for `nanoff --nanodevice --serialport /dev/ttyUSB0 --devicedetails`
- UART checks:
  - `nanoff --listports` reports `/dev/ttyUSB0`.
  - `nanoff --nanodevice --listdevices` reports `No devices found`.
  - `--devicedetails` fails with `Error E2001` at all tested baud rates: 1500000, 921600, 460800, 230400, 115200.
- Conclusion: Serial transport path is present at host level, but nanoFramework wire-protocol handshake is not currently discoverable over UART despite a fully passing SWD startup gate.

### 2026-04-08 15:37:19 UTC [INFO]
- Git rev: 4391075 (working tree with local diagnostic patches)
- Command(s): iterative firmware regression tests (rebuild + reflash + UART enumerate), including:
  - removed custom `g_CLR_RT_ExecutionEngine.flags` mutation from `nf-native/target-overrides/nanoHAL.cpp`
  - pinned interpreter build to `NF_INTERPRETER_REF=8bc239bd2` with `NF_UPDATE_INTERPRETER=0`
  - restored minimal profile clock path (`ENABLE_HSI_PLL=0`)
  - forced upstream/reference `nanoHAL.cpp` in `toolchain/build-native.sh`
  - added `nf-native/target-overrides/target_common.c` to map debug COM to USART3 and baud to 115200
- Firmware artifacts flashed: `build/nanoBooter.bin` @ `0x08000000`, `build/nanoCLR.bin` @ `0x08004000`
- UART results after each reflash:
  - `nanoff --nanodevice --serialport /dev/ttyUSB0 --baud 115200 --listdevices` => `No devices found`
  - `nanoff --nanodevice --serialport /dev/ttyUSB0 --baud 115200 --devicedetails` => `Error E2001`
  - same behavior persists at 921600
- Additional config finding:
  - generated target had debug COM defaulting to handle 1 (USART1) before `target_common.c` override; override changed this to COM3 but did not restore enumeration.
- Conclusion: wiring/host permissions are not the blocker; a firmware-side wire-protocol initialization path is still broken in current stack despite managed CLR startup being healthy.

### 2026-04-08 15:57:51 UTC [PASS]
- Git rev: 4391075 (working tree with local diagnostic patches)
- Command(s): `nanoff --nanodevice --serialport /dev/ttyUSB0 --baud 115200 --devicedetails`
- Result highlights:
  - HAL build info reported: `nanoCLR running @ M0DMF_CUBLEY_F407`
  - Target/platform correctly identified: `M0DMF_CUBLEY_F407` / `STM32F4`
  - Managed assemblies enumerated:
    - `BlinkBringup, 0.0.0.0`
    - `mscorlib, 1.17.11.0`
    - `System.Device.Gpio, 1.1.57.0`
    - `nanoFramework.Runtime.Events, 1.11.32.0`
    - `System.Threading, 1.1.52.34401`
  - Native assemblies enumerated, including:
    - `nanoFramework.Hardware.Stm32 v100.0.5.1`
    - `System.Device.Gpio v100.1.0.6`
    - `System.Device.I2c v100.0.0.2`
    - `System.Device.Spi v100.1.2.0`
- Conclusion: UART wire-protocol connectivity is confirmed working again at 115200 and managed deployment is recognized on-device; immediate root cause of earlier E2001 failures was the USB-UART adapter path, not the CLR assembly startup path.

### 2026-04-08 16:05:12 UTC [PASS]
- Git rev: 4391075 (working tree with local diagnostic patches)
- Command(s):
  1. `st-flash reset`
  2. `nanoff --nanodevice --serialport /dev/ttyUSB0 --baud 115200 --deploy --image tests/BlinkBringup/bin/Release/latest.deploy.bin`
  3. `nanoff --nanodevice --serialport /dev/ttyUSB0 --baud 115200 --devicedetails`
- Result: Deploy exited 0. Post-deploy devicedetails confirmed all 5 managed assemblies live on device.
  - `BlinkBringup, 0.0.0.0`
  - `mscorlib, 1.17.11.0`
  - `System.Device.Gpio, 1.1.57.0`
  - `nanoFramework.Runtime.Events, 1.11.32.0`
  - `System.Threading, 1.1.52.34401`
- LED (PA2 / LED_STATUS): toggling at 1 Hz from managed C# `BlinkBringup.Program.Main()` loop.
- Conclusion: Full managed code bring-up complete. Managed IL executing on STM32F407, GPIO output confirmed via hardware, wire-protocol deployment via nanoff confirmed working end-to-end.

### 2026-04-08 16:26:18 UTC [PASS]
- Correction to previous LED conclusion:
  - Symptom observed: managed assemblies deployed and visible, but LED did not blink after cold reset.
  - Root cause: GPIOA peripheral clock was not enabled at board startup in custom board init.
    - Evidence before fix (post-reset register read):
      - `RCC_AHB1ENR = 0x00101002` (GPIOAEN bit 0 clear)
      - `GPIOA_MODER = 0xA8000000` (PA2 mode not set)
    - This prevented managed GPIO access to PA2 (`LED_STATUS`) from taking effect.
- Permanent firmware fix:
  - File changed: `nf-native/board_cubley.cpp`
  - Added in `boardInit()` after `stm32_clock_init()`:
    - `RCC->AHB1ENR |= RCC_AHB1ENR_GPIOAEN;`
- Validation after rebuild/reflash/redeploy:
  1. Rebuilt firmware (`toolchain/build-native.sh`, profile `minimal`)
  2. Flashed `build/nanoBooter.bin` and `build/nanoCLR.bin`
  3. Deployed `tests/BlinkBringup/bin/Release/latest.deploy.bin`
  4. Verified post-reset registers without manual poke:
     - `RCC_AHB1ENR = 0x00101003` (GPIOAEN set)
     - `GPIOA_MODER = 0xA8000010` (PA2 output)
     - `GPIOA_ODR = 0x00000004`
  5. User confirmation: LED is flashing.
- Conclusion: Managed LED blink is now robust across reset/power cycle; issue fixed in firmware startup path.

### 2026-04-08 22:00:30 UTC [INFO]
- Git rev: a9bb2bd (working tree with local diagnostic/tooling patches)
- Command(s):
  - Recreated missing GDB probe command files under `.debug/` and corrected probe sequencing (`reset halt` -> set breakpoint -> `reset run`) for one-shot startup-gate probes.
  - Refreshed probe addresses from current `build/nanoCLR.elf` symbols/disassembly:
    - `CreateInstance` `0x0801434C`
    - `ResolveAll` `0x0802D588`
    - `After ResolveAll` `0x08019D9C`
    - `PrepareForExecution` `0x0802E854`
    - `NewThread` `0x080320E0`
    - `Execute_IL` `0x08009788`
    - `NativeWrite` `0x0801F5BC`
  - Probed `NativeWrite` argument registers at runtime (`r5=0x2`) to verify managed write targets pin index 2 (PA2).
- Result:
  - Pin mapping did not regress in vendored target content (PA2 remains `LED_STATUS`; managed pin argument observed as 2).
  - During one failing run, startup regressed at `ResolveAll` with `r0=0xA3000000` before IL execution.
- Conclusion: No evidence of PA2 remap regression. Intermittent no-LED episodes correlate with managed dependency resolution state, not pin-map drift.

### 2026-04-08 22:00:30 UTC [PASS]
- Git rev: a9bb2bd (working tree with local diagnostic/tooling patches)
- Command(s):
  - Updated `toolchain/compile-blink-test.sh` fallback bundling to include `nanoFramework.Runtime.Events.pe` automatically when available (from app output or `packages/` cache).
  - Rebuilt BlinkBringup and regenerated `tests/BlinkBringup/bin/Release/BlinkBringup.bin`.
  - Verified bundle composition with `toolchain/inspect_deploy_bundle.py` (5 NFMRK1 records including runtime events).
  - Reflashed deterministic baseline over SWD (`nanoBooter`, `nanoCLR`, deployment image).
  - Re-ran startup gate: all probes PASS (`ResolveAll HR=0x0`, `PrepareForExecution`, `NewThread`, `Execute_IL`, and `NativeWrite` all hit).
  - User power-cycled board and confirmed LED activity restored.
- Artifact:
  - `tests/BlinkBringup/bin/Release/BlinkBringup.bin` (full-stack fallback bundle)
- Conclusion: Build/deploy process is stable again for this target; managed startup and PA2 GPIO path are both validated after power cycle.
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

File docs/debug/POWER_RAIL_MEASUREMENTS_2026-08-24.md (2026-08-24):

# Power Rail Measurements - 2026-08-24

## 12 V Rail

Rise time: 6.2 ms

SCPI automatic 10-90% rise time: 5.70 ms
Top: 12.0 V
Maximum: 12.1 V
Startup shape: monotonic; no visible ringing, droop, or restart

### Steady-State Ripple (Unloaded/Bench Bring-Up State)

Probe: CH2, 10X, AC coupled at C16 pin 1 with a very short nearby GND connection
Scope: 20 MHz bandwidth limit, 20 mV/div

- DC verification before AC coupling: 12.0 V mean and RMS, 12.1 V top and maximum
- 1 us/div after AC-coupling settling: 32.9 mVpp to 56.5 mVpp; approximately 2.0 mVrms to 7.5 mVrms
- 100 us/div: 94.6 mVpp to 101.7 mVpp; approximately 9 mVrms
- Wide capture shows low-load burst/PFM packets at approximately 65 kHz repetition
- Worst displayed envelope is approximately 0.85% of the 12 V rail
- No oscillatory runaway, rail collapse, or slower instability was observed

## 3.3 V Rail

Rise time: 2.96 ms

SCPI automatic 10-90% rise time: 3.28 ms
Top: 3.30 V
Maximum: 3.35 V
Startup shape: monotonic; no visible ringing, droop, or restart

### Steady-State Ripple (Unloaded/Bench Bring-Up State)

Probe: CH2, 10X, AC coupled across C12 with a very short nearby GND connection
Scope: 20 MHz bandwidth limit, 20 mV/div

- 1 us/div: 39.5 mVpp to 59.8 mVpp over eight acquisitions; 5.3 mVrms to 5.9 mVrms
- 100 us/div: 56.9 mVpp, 5.32 mVrms, maximum +30.6 mV, minimum -37.5 mV
- One acquisition measured the expected switching frequency at 399 kHz
- Waveform shows low-load burst/PFM packets; automatic MHz frequency readings are false edge counts on switching spikes
- No slower ripple excursion or instability was observed at 100 us/div

## Setup Observation

With ST-Link/SWD and USB-UART attached while VIN was off, the 3.3 V rail was pre-biased to about 0.95 V. With both cables disconnected, the repeat startup capture began at 6.25 mV. Treat powered debug/USB connections as back-power paths during rail testing.

## Remaining

- Repeat both ripple measurements under representative and worst-case rail loads.
- Measure rail response to load steps, including undershoot, overshoot, settling time, and cross-rail coupling.

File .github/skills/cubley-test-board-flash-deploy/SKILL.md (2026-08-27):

---
name: cubley-test-board-flash-deploy
description: "Use when interacting with the CUBLEY_F407_0_5 test board: derive the active flash layout from build artifacts, flash nanoBooter and nanoCLR, deploy CubleyControl, and confirm runtime state. Keywords: Cubley test board, nanoBooter flash, nanoCLR flash, payload flash, managed deployment, st-flash, nanoff, flash layout."
---

# Cubley Test Board Flash/Deploy

## Purpose

Build, flash, deploy, and verify `CUBLEY_F407_0_5` using the layout encoded by
the artifacts being flashed.

## Source of Truth

Derive addresses from the generated files before every firmware flash:

- `firmware/nf-interpreter/build/nanoBooter.map`
- `firmware/nf-interpreter/build/nanoCLR.map`
- `firmware/nf-interpreter/build/nanoBooter.elf`
- `firmware/nf-interpreter/build/nanoCLR.elf`

Generated maps are the primary source. ELF program headers and symbols are the
independent fallback and cross-check because they travel with the linked image.
Checked-in linker scripts, build-script defaults, configuration names, and
historical layout tables are supporting evidence only.

Raw `.bin` files contain bytes but no load address. Use them only to determine
image size. Never infer an address from a filename or from Debug/Release labels.

## Layout Discovery

Run this procedure after every build and before every flash:

1. If maps are present, inspect each map's `Memory Configuration` and deployment
   symbols:
   - `grep -A20 '^Memory Configuration' firmware/nf-interpreter/build/nanoBooter.map`
   - `grep -A20 '^Memory Configuration' firmware/nf-interpreter/build/nanoCLR.map`
   - `grep -E '__deployment_(start|size)__' firmware/nf-interpreter/build/nanoCLR.map`
2. Read linked load addresses from the ELF program headers. Use these as the
   fallback when maps are absent and as a cross-check when maps are present:
   - `arm-none-eabi-readelf -lW firmware/nf-interpreter/build/nanoBooter.elf`
   - `arm-none-eabi-readelf -lW firmware/nf-interpreter/build/nanoCLR.elf`
   - Use the first flash-resident `LOAD` physical address for each image.
3. If map deployment symbols are unavailable, read them from the ELF symbol
   table:
   - `arm-none-eabi-nm -n firmware/nf-interpreter/build/nanoCLR.elf | grep -E '__deployment_(start|size)__'`
4. Read raw image sizes:
   - `stat -c '%n %s' firmware/nf-interpreter/build/nanoBooter.bin firmware/nf-interpreter/build/nanoCLR.bin`
5. Read the connected target's flash capacity with `st-info --probe`.
6. Calculate image ends as `load_address + bin_size` and verify:
   - nanoBooter does not overlap nanoCLR.
   - nanoCLR does not overlap deployment.
   - deployment start plus deployment size does not exceed target flash.
7. Refuse to flash if available map and ELF addresses disagree, neither source
   provides the required addresses and deployment symbols, an overlap exists,
   or the `.elf` adjacent to a `.bin` is absent.

## Primary Artifacts

- `firmware/nf-interpreter/build/nanoBooter.bin`
- `firmware/nf-interpreter/build/nanoCLR.bin`
- `firmware/nf-interpreter/build/nanoBooter.elf`
- `firmware/nf-interpreter/build/nanoCLR.elf`
- `software/nanoFramework/build/CubleyControl/latest.deploy.bin`

## Refresh Flow

From the repository root:

1. Build firmware:
   - `./firmware/build-flash-cubley.sh build`
2. Run the complete Layout Discovery procedure above and record the derived
   booter, CLR, deployment start, and deployment size values.
3. Flash using explicit values derived from the current artifacts:
   - `./firmware/build-flash-cubley.sh flash --bootaddr <booter-start> --clraddr <clr-start> --deployaddr <deployment-start> --deploysize <deployment-size> --reset`
4. Build the managed bundle:
   - `cd software/nanoFramework`
   - `./toolchain/build-CubleyControl.sh build --project CubleyControl/CubleyControl.nfproj --configuration Debug`
5. Deploy over the wire protocol:
   - `./toolchain/deploy-CubleyControl.sh --reset`
6. Verify identity:
   - `nanoff --nanodevice --serialport /dev/ttyUSB0 --baud 921600 --devicedetails`

For a direct SWD payload fallback, write `latest.deploy.bin` only at the
deployment start derived from the current map or ELF symbols. Confirm the bundle
size fits within the derived deployment size before writing.

## Expected Signals

- Device details reports `nanoCLR running @ CUBLEY_F407_0_5`.
- All assemblies required by the current managed deployment manifest are listed.
- Native `CubleyNative` version and checksum match the managed build.
- No assembly resolver or link failure is reported.

## Guardrails

- Do not erase deployment unless explicitly required.
- Do not trust hardcoded addresses or build-script defaults; pass derived values
   explicitly to flash commands.
- Do not mix firmware and managed artifacts from different interop checksums.
- Use `/dev/ttyUSB0` only for nanoFramework wire protocol operations.
- Validate user CLI commands on USB CDC separately; that console is not available from the container.
- Record significant flash/deploy/probe runs in `docs/debug/BRINGUP_TEST_LOG.md`.

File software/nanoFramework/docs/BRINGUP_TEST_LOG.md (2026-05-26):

# DiSEqC nanoFramework Bring-up Test Log

This file tracks factual checkpoints, commands, and outcomes for the STM32F407 bring-up.

## Device under test
- Target: M0DMF_CUBLEY_F407
- MCU: STM32F407
- Bootloader: nanoBooter present

## 2026-04-07 Timeline

### 1) Firmware and flash layout validation
- Confirmed linker/storage intent:
  - nanoBooter: 0x08000000-0x08004000
  - nanoCLR: 0x08004000-0x080C0000
  - Deployment: 0x080C0000-0x08100000
- Rebuilt native firmware with minimal profile.
- Enabled config block for minimal profile in build script.
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

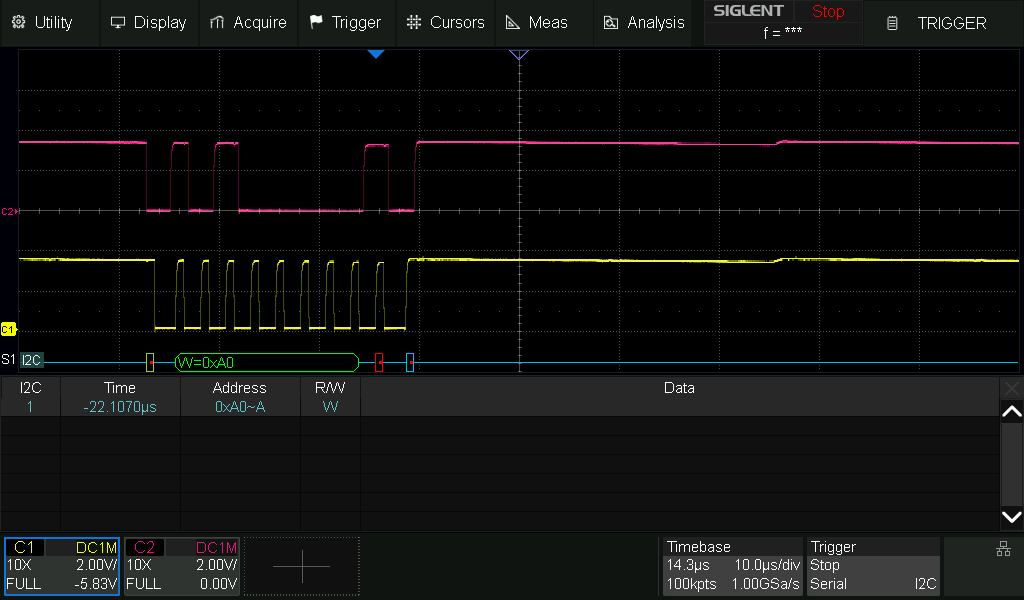
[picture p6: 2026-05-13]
docs/tests/2026-05-13_I2C3_FRAM_probe.png

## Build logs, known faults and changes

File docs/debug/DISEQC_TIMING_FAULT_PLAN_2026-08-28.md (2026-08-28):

# DiSEqC Symbol-Timing Fault Isolation and Fix Plan

Date: 2026-08-28

## Objective

Identify the source of the excessive DiSEqC symbol duration, replace the timing-sensitive managed transmit loop with deterministic timing, and verify the complete transmit path from MCU gate output to J8 against the DiSEqC bus specification.

## Evidence and limits

### Current measurement

The 2026-08-28 stopped-waveform analysis at J8 found:

- Carrier: 22.106 kHz (45.236 us period), based on 50 accepted periods.
- Logical-zero marks: 1.110 ms and 1.140 ms.
- Following spaces: 0.720 ms and 0.670 ms.
- Complete symbol times: 1.830 ms and 1.810 ms.
- Envelope-bin and edge uncertainty: approximately +/-10 us.
- Capture integrity warning: the descriptor declared 10,000,000 samples, but only 5,000,000 samples were returned. Only two complete symbols were available.

The carrier is correct. The excessive symbol duration is in the carrier-envelope gate timing.

### Specification-derived acceptance limits

Source: `.debug/diseqc_spec.pdf`, with searchable extraction in `.debug/diseqc_spec.txt`.

DiSEqC Bus Functional Specification 4.2 states:

- Base timing: 500 us +/-100 us.
- Logical zero: nominal 1.0 ms mark followed by 0.5 ms space.
- Logical one: nominal 0.5 ms mark followed by 1.0 ms space.
- Carrier: nominal 22 kHz +/-20%.
- End of message: at least 6 ms silence.
- Signalling amplitude: 650 mVpp +/-250 mVpp.

Protocol gates:

| Quantity | Allowed range |
| --- | ---: |
| Short interval | 0.400-0.600 ms |
| Long interval | 0.800-1.200 ms |
| Complete symbol, derived from the interval limits | 1.200-1.800 ms |
| Carrier | 17.6-26.4 kHz |
| End silence | >=6 ms |
| Bus amplitude | 0.400-0.900 Vpp |

The measured zero mark is within the long-interval limit, but both measured spaces exceed the 0.600 ms short-interval maximum. Both complete symbols exceed the derived 1.800 ms maximum even before allowing for the approximately 10 us analysis quantization. The approximately 0.78 Vpp amplitude and 22.106 kHz carrier pass.

Use tighter engineering targets after the fix to retain margin:

- Short interval: 0.480-0.520 ms.
- Long interval: 0.980-1.020 ms.
- Symbol: 1.480-1.520 ms.
- Run-to-run boundary jitter: <=20 us where the analog envelope permits it.

## Leading fault hypothesis

The current transmitter performs every envelope transition from managed code:

1. `PwmChannel.Start()` or `PwmChannel.Stop()` crosses the CLR/native boundary.
2. `DelayMicroseconds()` repeatedly calls `DateTime.UtcNow` in managed code.
3. The next managed/native PWM call occurs only after that delay returns.

The measured long mark exceeds its requested delay by 110-140 us, while the short space exceeds its requested delay by 170-220 us. A complete symbol gains approximately 310-330 us. That shape is consistent with fixed transition/interop overhead plus managed runtime scheduling, not with a carrier-frequency error.

Do not make subtractive calibration of the managed delays the production fix. It may pass one runtime load while remaining sensitive to garbage collection, USB, Ethernet/MQTT, debugger state, and firmware changes.

## Phase 1 — improve and preserve the baseline

1. Copy the stopped waveform, preamble, screenshot, and analysis JSON into a dated repository artifact directory. Retain hashes of the raw files.
2. Correct or explicitly document the scope descriptor/sample-count discrepancy before relying on full-frame duration.
3. Capture a complete `E0 10 38 F0` frame with enough post-trigger depth for all 36 encoded bits (eight data bits plus odd parity per byte) and at least 10 ms of trailing silence.
4. Extend the offline analyzer output to include every complete mark/space pair, decoded bit value, per-class min/mean/max, total frame duration, and pre/post silence. Fail analysis on truncated runs or an unexpected encoded bit sequence.
5. Repeat at least 10 transmissions to establish distributions rather than two samples.

Exit criterion: a reproducible baseline containing both logical-zero and logical-one intervals, complete-frame timing, and no unexplained acquisition truncation.

## Phase 2 — separate delay, transition, and analog-path contributions

Use two scope channels where possible:

- Channel 1: PD12 or TP15/DSQIN-A, referenced to board ground.
- Channel 2: J8 through the already validated AC-coupled 10x setup.

Confirm probe attenuation, channel setting, coupling, grounding, and safe voltage range before treating the capture as a physical measurement.

Run these bounded diagnostics:

1. **GPIO-only delay test:** toggle an otherwise safe diagnostic GPIO around managed `DelayMicroseconds(500)` and `DelayMicroseconds(1000)`. This measures the managed clock loop and GPIO-call overhead without PWM.
2. **PWM transition test:** emit repeated 500/1000 us PWM gates without frame encoding. Compare PD12 boundary timing with the requested schedule.
3. **Path latency test:** compare corresponding PD12 and J8 envelope edges. A stable small offset implicates software timing; variable or asymmetric propagation implicates LNBH26/path behavior.
4. **Load sensitivity test:** repeat idle, Ethernet/MQTT active, USB CDC traffic active, and debugger detached. Record min/mean/max and outliers for each interval class.
5. **Pattern test:** transmit frames chosen to provide long runs of zeros, long runs of ones, and alternating values. Include odd parity in the expected sequence.

Decision rule:

- If PD12 already has the excess duration, fix firmware timing.
- If PD12 passes but J8 fails, investigate LNBH26 EXTM/TEN gating and the C31-to-1-kOhm modification path.
- If only managed GPIO timing fails, `DateTime.UtcNow`/runtime scheduling is dominant.
- If GPIO timing passes but PWM gating fails, repeated `PwmChannel.Start()`/`Stop()` dispatch or timer-channel behavior is dominant.

## Phase 3 — implement deterministic native transmission

Preferred production design: one native call owns an entire frame transmission. Managed code validates/builds the frame and reports the result; it does not schedule individual symbol edges.

1. Append a `CubleyNative` InternalCall such as `LNBH26.NativeTransmitDiseqc(byte[] frame, int offset, int count)`. Do not reorder or repurpose existing interop slots.
2. In target-local native firmware, validate the frame length and encode each byte MSB-first with odd parity, matching `DiseqcFrameCodec`.
3. Keep TIM4 channel 1 as the 22 kHz carrier source on PD12.
4. Use a dedicated internal basic timer, provisionally TIM6 at 1 MHz, as a one-shot boundary scheduler for 500 and 1000 us intervals. TIM7 is the fallback subject to the final DAC/timer resource audit. At each callback, use the ChibiOS ISR-safe PWM channel enable/disable operation and schedule the next boundary. TIM2 must not be used: this target already assigns it to the ChibiOS system-timer driver through `STM32_ST_USE_TIMER 2`.
5. Block only the calling managed thread on a bounded completion event/semaphore. Do not busy-wait for the approximately 54 ms four-byte frame and do not mask interrupts for the frame duration.
6. Force carrier off on completion, validation error, timeout, or exception. Return a specific status and publish detailed native diagnostics without adding noisy user-facing console output.
7. Preserve at least 6 ms end silence; retain the current 15 ms inter-frame/guard gap unless a protocol sequence requires a different documented gap.
8. Audit TIM4 sharing with motor channels and confirm that TIM6 is not selected as a DAC trigger or used by another native subsystem before enabling GPT support. The transmitter must not silently reconfigure a timer used by an active peripheral. Enabling TIM6 requires target-local software configuration (`HAL_USE_GPT=TRUE` and `STM32_GPT_USE_TIM6=TRUE`); it does not require a PCB change or external timer pin.
9. Remove `EmitDiseqcBit()` and `DelayMicroseconds()` from the production frame path after native transmission passes. Continuous-tone behavior may remain separate, but carrier ownership must be explicit and mutually exclusive.

A TIM6 ISR introduces only symbol-boundary interrupts, unlike a 22 kHz periodic ISR. If the final resource audit rejects TIM6, use TIM7 or another unowned hardware timer, or use a timer/DMA edge schedule; do not return to managed edge timing. Keep the ISR limited to deterministic state advancement, PWM gating, next-deadline programming, and completion signalling.

## Phase 4 — software verification before hardware deployment

1. Add deterministic tests for:
   - MSB-first byte order.
   - Odd parity for `00`, `FF`, `E0`, `10`, `38`, and `F0`.
   - Exact 500/1000 us schedule generation for zeros and ones.
   - 36 encoded bits and nominal 54 ms data duration for `E0 10 38 F0`.
   - Frame-length rejection and timeout cleanup with carrier forced off.
2. Run the interop guard and checksum checks after appending the InternalCall.
3. Build both managed and native firmware from the target-local source of truth.
4. Verify that generated community-target files match target-local inputs; do not edit generated target files directly.
5. Deploy matching native firmware and managed assemblies together because the interop checksum will change.

Exit criterion: tests, interop guard, managed build, and native build all pass with the carrier-off failure invariant covered.

## Phase 5 — scope acceptance

Capture at least 30 complete `E0 10 38 F0` transmissions, including idle and Ethernet/MQTT/USB load cases. Analyze raw samples, not scope packet-wide automatic period measurements.

Acceptance requires:

- Every short and long interval inside the protocol gates.
- Engineering targets met across normal load, or a documented margin analysis if analog edge detection prevents the tighter target.
- Every symbol inside 1.200-1.800 ms; target 1.480-1.520 ms.
- Correct decoded 36-bit data/parity sequence.
- Nominal data duration approximately 54 ms for the four-byte frame.
- Carrier inside both the DiSEqC range and the board's existing 20-24 kHz LNBH26 target.
- J8 amplitude 0.400-0.900 Vpp.
- At least 6 ms trailing silence and the intended inter-frame gaps.
- Carrier forced off after success, rejected input, and induced timeout/error.
- No timing regression when MQTT, Ethernet interrupts, USB CDC, and the debugger state vary.

Append the final commands, artifact paths, measured distributions, and conclusion to the bring-up log only after the acceptance capture is complete.

## Immediate next action

Perform Phase 1 recapture and the Phase 2 dual-node/pattern measurements before modifying interop. They will confirm that the fault is present at PD12 and quantify the exact managed delay versus PWM-transition contributions. In parallel, the TIM4/TIM6/TIM7 ownership audit can proceed without changing hardware state. TIM2 has already been excluded because it is the active ChibiOS system timer.

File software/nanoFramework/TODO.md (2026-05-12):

# nanoFramework TODO

## Current Focus: Build Chain Reliability

### Current Decision (2026-02-23)

- Use `./toolchain/compile-managed.sh` as the required local/pre-commit quality gate.
- Treat full `msbuild ... /t:Build` on this Linux host as blocked by nanoFramework metadata processor dependency/runtime mismatch.
- Generate deployable PE artifacts from a known-good packaging environment (e.g., Windows CI/dev box) until Linux metadata processor path is fixed.
- Do **not** rely on `libgdiplus` as the primary fix path for the current failure mode.

- [x] Make full `msbuild ... /t:Build` pass on Linux host (not only `/t:Compile`) via scripted Linux MDP override in `toolchain/build-chain.sh`.
- [x] Resolve `System.Drawing.Common` load failure in nanoFramework metadata processor (`NFProjectSystem.MDP.targets`) using `NF_MDP_MSBUILDTASK_PATH` + Mono `System.Drawing.dll` overlay.
- [x] Validate fix path for Linux-hosted metadata processor (current extension bundle includes a Windows-targeted `System.Drawing.Common` assembly).
- [x] Add a reproducible local build wrapper for full build (with required env vars/paths).
- [x] Document known-good build commands and prerequisites in `software/nanoFramework/README.md`.

## Managed Dependency Hygiene

- [x] Remove unused direct references/packages not required by current managed code.
- [x] Keep `System.Net` aligned to M2Mqtt expected version (`1.11.36`) to avoid CS1702 mismatch.
- [ ] Revisit remaining remap warnings now that full build chain is stable.
- [x] Keep `./toolchain/compile-managed.sh` as the safe pre-commit gate until metadata processor issue is fixed.

## STM32-Only Cleanup

- [ ] Remove residual ESP32 references from tooling/docs/scripts and enforce STM32-only terminology in this repository.

## Managed/Interop Test Coverage

- [x] Add host-only unit test project for pure managed logic (`tests/DiSEqC_Control.Tests`) and run it on Linux.
- [x] Cover `RuntimeConfiguration` parsing/validation and `ParityHelper` behavior with unit tests.
- [x] Add host-side interop contract tests for managed/native boundaries (starting with W5500 socket API status/parameter handling).
- [ ] Add hardware smoke-test checklist for W5500 RX/TX and USB wire protocol after native implementation lands.
- [ ] PAUSED: add further host-side test construction until Phase 3 native W5500 transport is implemented.

## Implementation Plan (Phased)

### Phase 1: Managed Test Foundation (completed)

- [x] Create host-only unit test project and run in Linux CI/local.
- [x] Add pure-logic tests for configuration and parity behaviors.
- [x] Document how to run unit tests in `software/nanoFramework/README.md`.

### Phase 2: Interop Contract Tests (paused)

- [x] Add host-side tests for managed/native contract behavior of W5500/DiSEqC/LNB interop API (host-safe reflection contract checks).
- [ ] Add runtime/on-device interop tests for parameter validation, lifecycle, and timeout/error paths (host CLR cannot invoke InternalCall methods).
- [ ] PAUSED pending Phase 3: defer additional test expansion until real native transport behavior exists.

### Phase 3: Real W5500 Native Transport (active focus)

- [x] Replace stub behavior in `nf-native/w5500_interop.cpp` with real RX/TX socket path.
- [x] Wire W5500 local IP/subnet/gateway/MAC defaults to runtime config + FRAM (`network.*`) via native `ConfigureNetwork` interop.
- [x] Reconcile board-level pin/config definitions required by W5500 runtime path.
- [x] Verify `cubley-uart` firmware profile build remains green in Docker.

### Phase 3.5: M2Mqtt Adapter Integration (in progress)

- [x] Create in-repo managed adapter implementing `nanoFramework.M2Mqtt.IMqttNetworkChannel` backed by `DiSEqC_Control.Native.W5500Socket`.
- [x] Add minimal M2Mqtt entry point to accept injected channel (in-repo overlay helper injecting `IMqttNetworkChannel`).
- [x] Keep current host/port constructor path intact as fallback to reduce rollout risk.
- [x] Update `Program.cs` to select transport mode (`system-net` fallback vs `w5500-native` adapter) via runtime config key.
- [x] Add host contract tests for adapter behavior (connect/send/receive/close call routing + status mapping).
- [x] Add on-device MQTT smoke test against broker using W5500 adapter path.
- [x] Document adapter mode usage and rollback steps in `README.md` and testing guide.

### Phase 4: USB Wire Protocol Migration

- [x] Define target USB behavior for deployment/debug wire protocol (native USB as primary interface). See `docs/guides/USB_FIRST_PROFILE_CHECKLIST.md`.
- [ ] Implement required firmware startup/config changes for USB wire protocol. (Stage A implemented: `usb-first` profile + OTG/HAL USB flag wiring in `toolchain/build.sh`.)
- [ ] Update docs and test procedures for USB-first workflow.
- [ ] PAUSED: hardware-dependent USB validation is deferred until first working board is available.

### Phase 5: Hardware Validation

- [ ] Run board-level smoke tests for W5500 connectivity and stability.
- [ ] Validate USB wire protocol end-to-end (connect/deploy/debug).
- [ ] Capture known-good validation matrix and rollback notes in docs.

## Deferred: Align to Latest Stable Everywhere

- [ ] Inventory latest stable versions for all nanoFramework packages in use.
- [ ] Upgrade in small batches with compile + build verification after each batch.
- [ ] Record rollback points per batch.
- [ ] Update docs once a fully verified baseline is reached.

## Deferred: Managed Project Rename

- [x] Rename managed project from `DiseqC` to `DiSEqC_Control`.
- [x] Rename managed project files/folders (`*.nfproj`, `*.sln`, and related paths) to match new project name.
- [x] Update C# namespaces from `DiseqC` to `DiSEqC_Control` across managed code.
- [x] Update native interop registration names/assembly identifiers and build scripts required by the rename.
- [x] Update docs and command examples to reference the new project name.
- [x] Re-run `./toolchain/compile-managed.sh` and `./toolchain/build-chain.sh` after rename (full build remains blocked by known `System.Drawing.Common` metadata processor issue).

## Managed Startup Preflight (idea)

- [ ] Add a minimal, always-completing managed hardware preflight at startup that probes core devices (W5500, LNBH26, FRAM, and other board-critical peripherals), records a per-device pass/fail bitmap + error details, and only then branches to main app behavior.
- [ ] Ensure preflight tolerates intentionally-missing hardware variants (for example, no W5500 fitted) without blocking remaining checks.
- [ ] Emit preflight summary to mailbox/diagnostic channel so failures are visible even when main app path is skipped.

## Temporary Diagnostics Cleanup

- [ ] Remove temporary deep CLR startup/resolve diagnostics in `toolchain/build.sh` (`CUBLEY_CLR_STARTUP_DIAG` and `CUBLEY_CLR_RESOLVE_PTR`) after startup regression risk is low and baseline tests are stable.

## Native/W5500 Follow-up

- [x] Replace W5500 interop stub behavior with real RX/TX socket path.
- [x] Implement real board pin configuration in `ConfigPins_I2C3()` (PA8/PC9 I2C3 open-drain AF4 setup).
- [ ] Validate runtime networking path on hardware once board is available.

## Deferred: Motor Control (after immediate hardware checks)

- [ ] Revisit native motor-enable interop/API surface after FRAM and board-level checks are completed.
- [ ] Define managed motor-control workflow (step, slew, tracking, timeout safety) and align native implementation.
- [ ] Add a dedicated motor bring-up test app with clear LED/telemetry pass-fail indicators.

## FRAM Hardware Checks (from bring-up)

- [ ] Verify FM24CL16B pin 7 (WP) is solidly tied low on assembled boards.
- [ ] Confirm FM24CL16B orientation/pin-1 alignment on PCB assemblies.
- [ ] Probe SDA/SCL bus levels during FRAM write transactions.
- [ ] Check continuity from MCU I2C3 lines (PA8/PC9) to FRAM pins.

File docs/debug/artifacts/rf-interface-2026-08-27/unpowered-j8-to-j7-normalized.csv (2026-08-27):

frequency_hz | normalized_trace_db | insertion_loss_db
950000000.0 | -1.987305 | 1.987305
951600000.0 | -1.90918 | 1.90918
953200000.0 | -1.914062 | 1.914062
954800000.0 | -1.928711 | 1.928711
956400000.0 | -1.855469 | 1.855469
958000000.0 | -1.889648 | 1.889648
959600000.0 | -1.845703 | 1.845703
961200000.0 | -1.816406 | 1.816406
962800000.0 | -1.806641 | 1.806641
964400000.0 | -1.777344 | 1.777344
966000000.0 | -1.713867 | 1.713867
967600000.0 | -1.694336 | 1.694336
969200000.0 | -1.601562 | 1.601562
970800000.0 | -1.5625 | 1.5625
972400000.0 | -1.499023 | 1.499023
974000000.0 | -1.489258 | 1.489258
975600000.0 | -1.44043 | 1.44043
977200000.0 | -1.411133 | 1.411133
978800000.0 | -1.39625 | 1.39625
980400000.0 | -1.37207 | 1.37207
982000000.0 | -1.337891 | 1.337891
983600000.0 | -1.308594 | 1.308594
985200000.0 | -1.28418 | 1.28418
986800000.0 | -1.308594 | 1.308594
988400000.0 | -1.303711 | 1.303711
990000000.0 | -1.269531 | 1.269531
991600000.0 | -1.298828 | 1.298828
993200000.0 | -1.274414 | 1.274414
994800000.0 | -1.279297 | 1.279297
996400000.0 | -1.293945 | 1.293945
998000000.0 | -1.323242 | 1.323242
999600000.0 | -1.328125 | 1.328125
1001200000.0 | -1.328125 | 1.328125
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

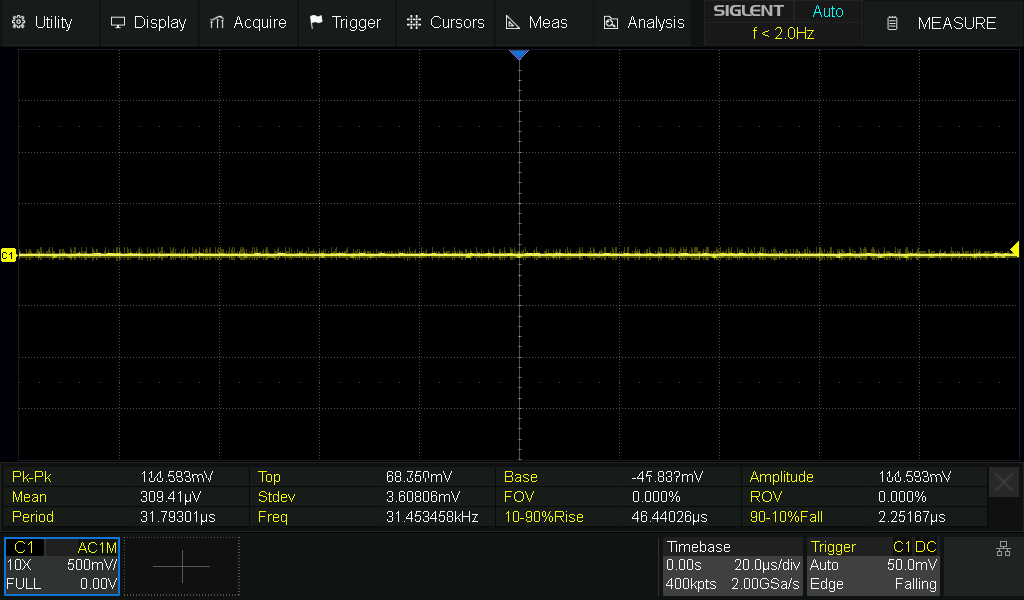
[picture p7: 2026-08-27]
docs/debug/artifacts/rf-interface-2026-08-27/20260827-scope-j8-lowband.png

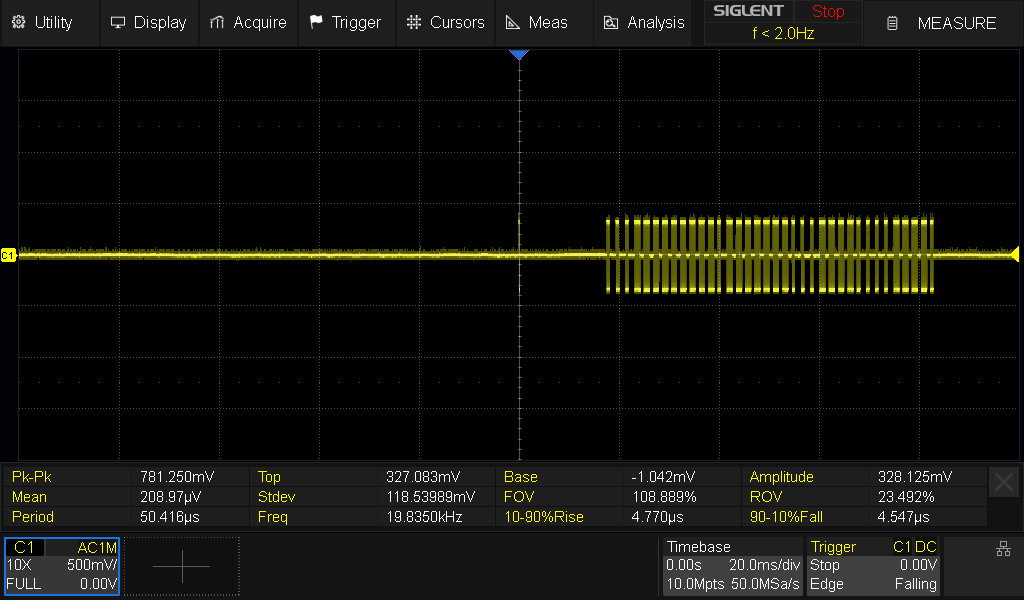
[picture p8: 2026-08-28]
docs/debug/artifacts/rf-interface-2026-08-27/20260828-scope-j8-diseqc-frame-e0-10-38-f0.png

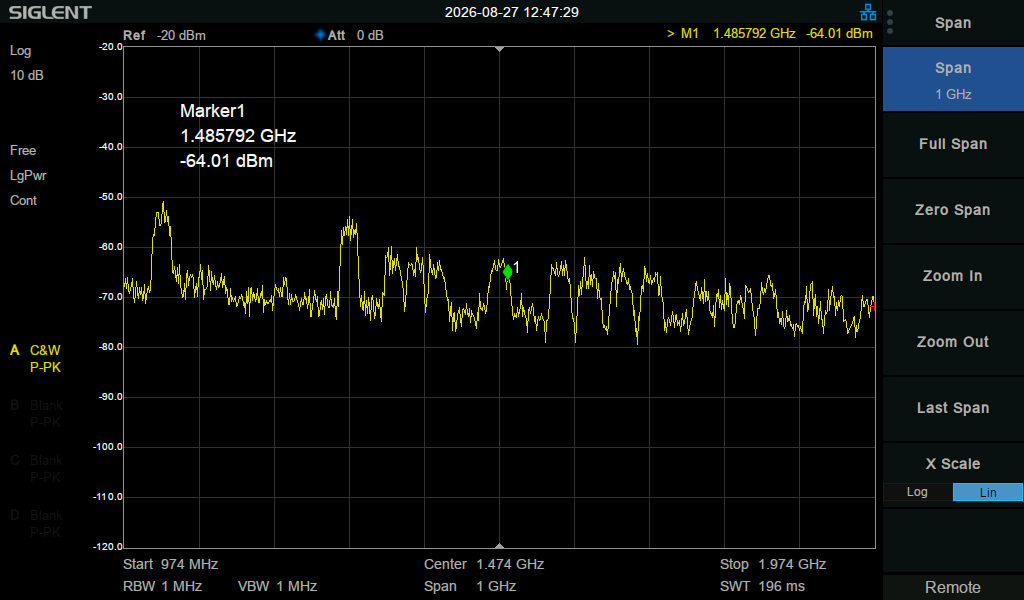
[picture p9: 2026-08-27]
docs/debug/artifacts/rf-interface-2026-08-27/20260827-lowband_horizontal_18v.png

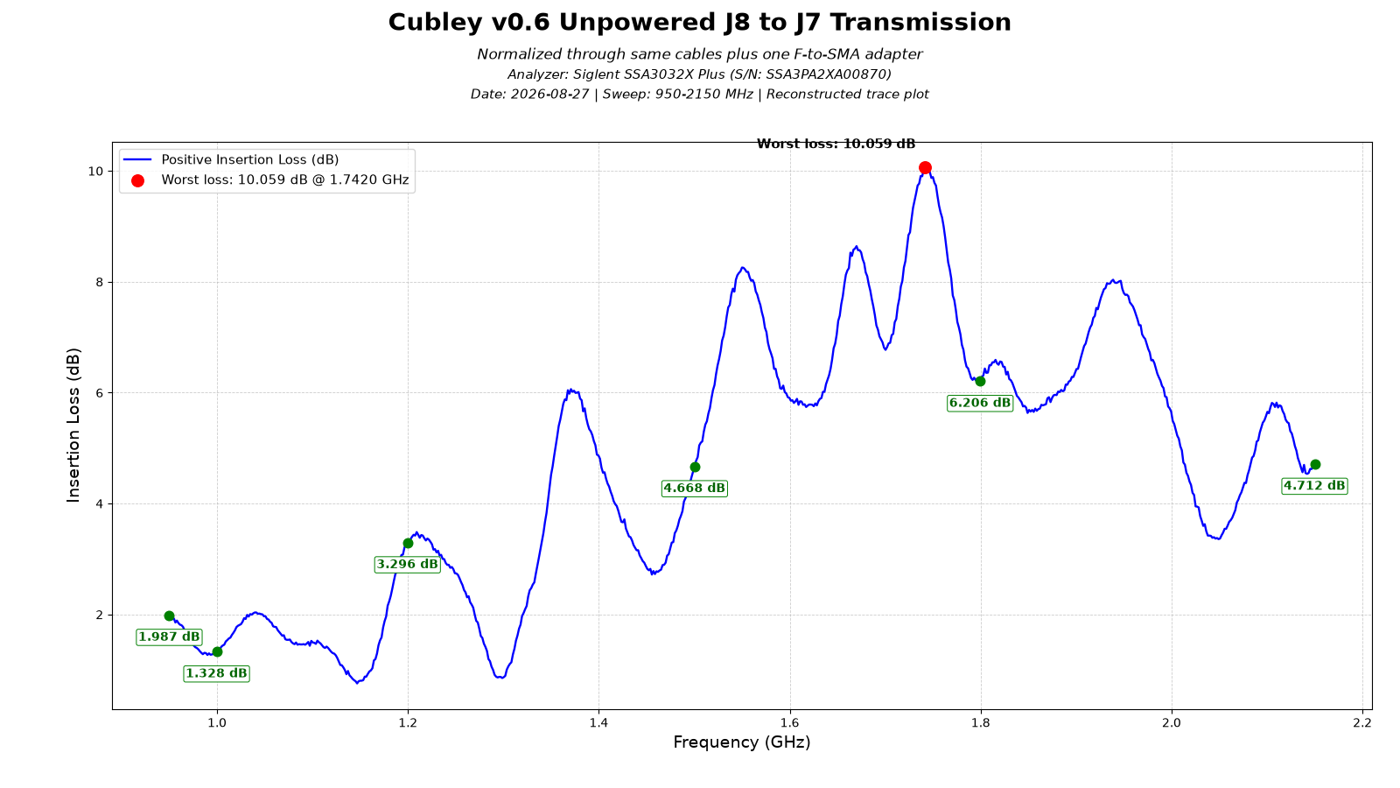
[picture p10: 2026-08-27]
docs/debug/artifacts/rf-interface-2026-08-27/unpowered-j8-to-j7-normalized.png

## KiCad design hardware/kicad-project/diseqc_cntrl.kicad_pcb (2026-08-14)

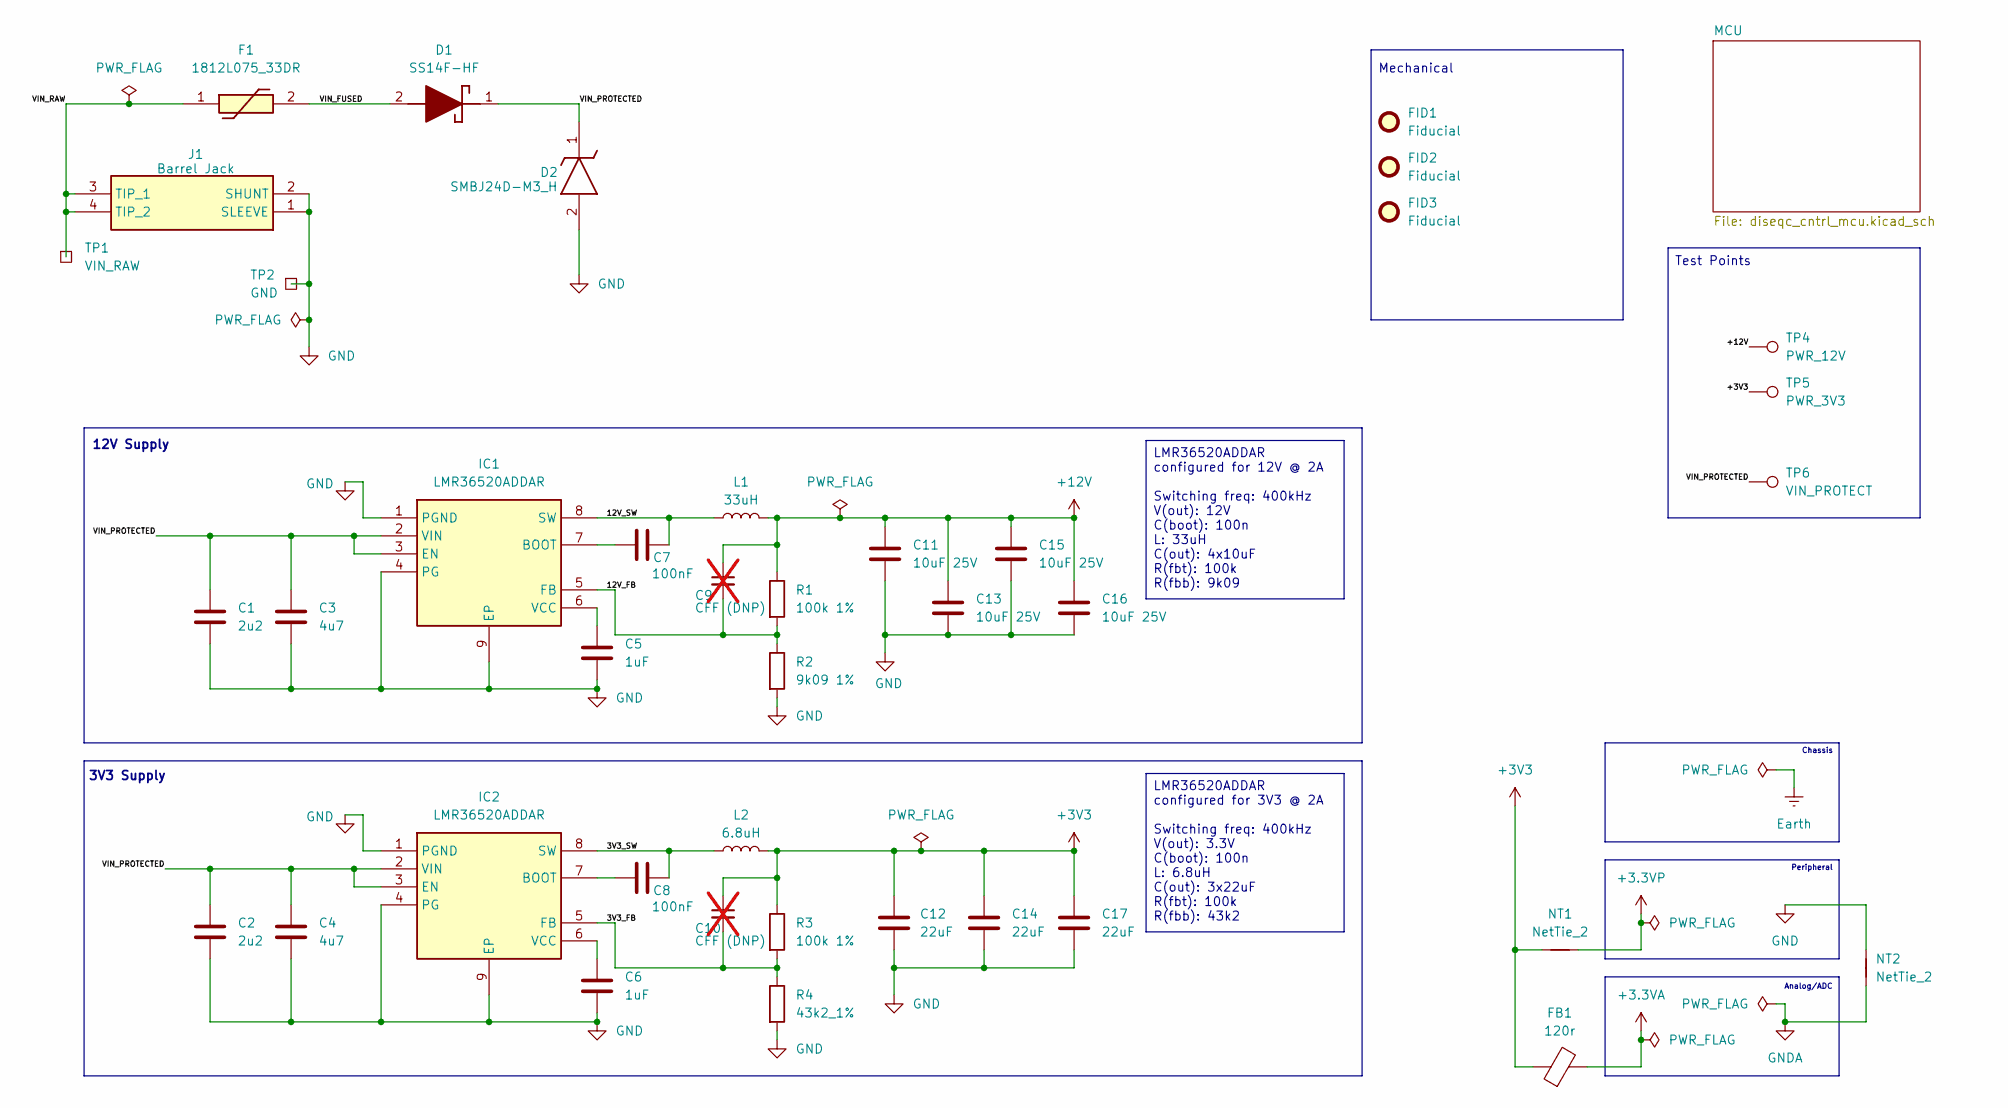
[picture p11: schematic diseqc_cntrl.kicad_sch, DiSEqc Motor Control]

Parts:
C1, C2: 2u2; C_0603_1608Metric; Part EMK063B7103KP-F; Mouser Part Number 81-GRM188R6YA225MA2D
C3, C4: 4u7; C_0603_1608Metric
C5, C6: 1uF; C_0603_1608Metric
C7, C8: 100nF; C_0603_1608Metric; Part EMK063B7103KP-F
C9, C10: CFF (DNP); not fitted
C11, C13, C15, C16: 10uF 25V; C_1206_3216Metric
C12, C14, C17: 22uF; C_0603_1608Metric; Tolerance 20%
D1: SS14F-HF; SODFL4626X120N; Mouser Part Number 750-SS14F-HF
D2: SMBJ24D-M3_H; DIOM5436X244N; Mouser Part Number 78-SMBJ24D-M3H
F1: 1812L075_33DR; 1812L010DR; Mouser Part Number 576-1812L075/33DR
FB1: 120r; L_0603_1608Metric
FID1, FID2, FID3: Fiducial; Fiducial_1mm_Mask2mm
IC1, IC2: LMR36520ADDAR; SOIC127P600X170-9N; Mouser Part Number 595-LMR36520ADDAR
J1: Barrel Jack; RASM742TRX; Mouser Part Number 502-RASM742TRX
L1: 33uH; WE-PD_1260_1245_1280_121054
L2: 6.8uH; INDPM5752X300N; Tolerance 20%
NT1, NT2: NetTie_2; NetTie-2_SMD_Pad2.0mm
R1, R3: 100k 1%; R_0603_1608Metric; Tolerance 1%; ToleranceRequirement <=1%
R2: 9k09 1%; R_0603_1608Metric
R4: 43k2_1%; R_0603_1608Metric; ToleranceRequirement <=1%
TP1: VIN_RAW; TestPoint_Pad_4.0x4.0mm
TP2: GND; TestPoint_Pad_4.0x4.0mm
TP4: PWR_12V; TestPoint_THTPad_D1.0mm_Drill0.5mm_annotated
TP5: PWR_3V3; TestPoint_THTPad_D1.0mm_Drill0.5mm_annotated
TP6: VIN_PROTECT; TestPoint_THTPad_D1.0mm_Drill0.5mm_annotated

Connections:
+3.3VA: FB1.2; also elsewhere on the board
+3.3VP: NT1.2; also elsewhere on the board
+3V3: C10.1, C12.1, C14.1, C17.1, FB1.1, L2.2, NT1.1, R3.1, TP5.1 (1_1); also elsewhere on the board
+12V: C9.1, C11.1, C13.1, C15.1, C16.1, L1.2, R1.1, TP4.1 (1_1); also elsewhere on the board
/3V3_FB: C10.2, IC2.5 (FB), R3.2, R4.1
/3V3_SW: C8.2, IC2.8 (SW), L2.1
/12V_FB: C9.2, IC1.5 (FB), R1.2, R2.1
/12V_SW: C7.2, IC1.8 (SW), L1.1
/VIN_FUSED: D1.2 (A), F1.2
/VIN_PROTECTED: C1.1, C2.1, C3.1, C4.1, D1.1 (K), D2.1 (K), IC1.2 (VIN), IC1.3 (EN), IC2.2 (VIN), IC2.3 (EN), TP6.1 (1_1)
/VIN_RAW: F1.1, J1.3 (TIP_1), J1.4 (TIP_2), TP1.1 (1_1)
GND: C1.2, C2.2, C3.2, C4.2, C5.2, C6.2, C11.2, C12.2, C13.2, C14.2, C15.2, C16.2, C17.2, D2.2 (A), IC1.1 (PGND), IC1.4 (PG), IC1.9 (EP), IC2.1 (PGND), IC2.4 (PG), IC2.9 (EP), J1.1 (SLEEVE), J1.2 (SHUNT), NT2.2, R2.2, R4.2, TP2.1 (1_1); also elsewhere on the board
GNDA: NT2.1; also elsewhere on the board
unnamed: C7.1, IC1.7 (BOOT)
unnamed: C5.1, IC1.6 (VCC)
unnamed: C8.1, IC2.7 (BOOT)
unnamed: C6.1, IC2.6 (VCC)

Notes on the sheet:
3V3 Supply
Test Points
12V Supply
Analog/ADC
Peripheral
Mechanical
Chassis
LMR36520ADDAR configured for 3V3 @ 2A Switching freq: 400kHz V(out): 3.3V C(boot): 100n L: 6.8uH C(out): 3x22uF R(fbt): 100k R(fbb): 43k2
LMR36520ADDAR configured for 12V @ 2A Switching freq: 400kHz V(out): 12V C(boot): 100n L: 33uH C(out): 4x10uF R(fbt): 100k R(fbb): 9k09

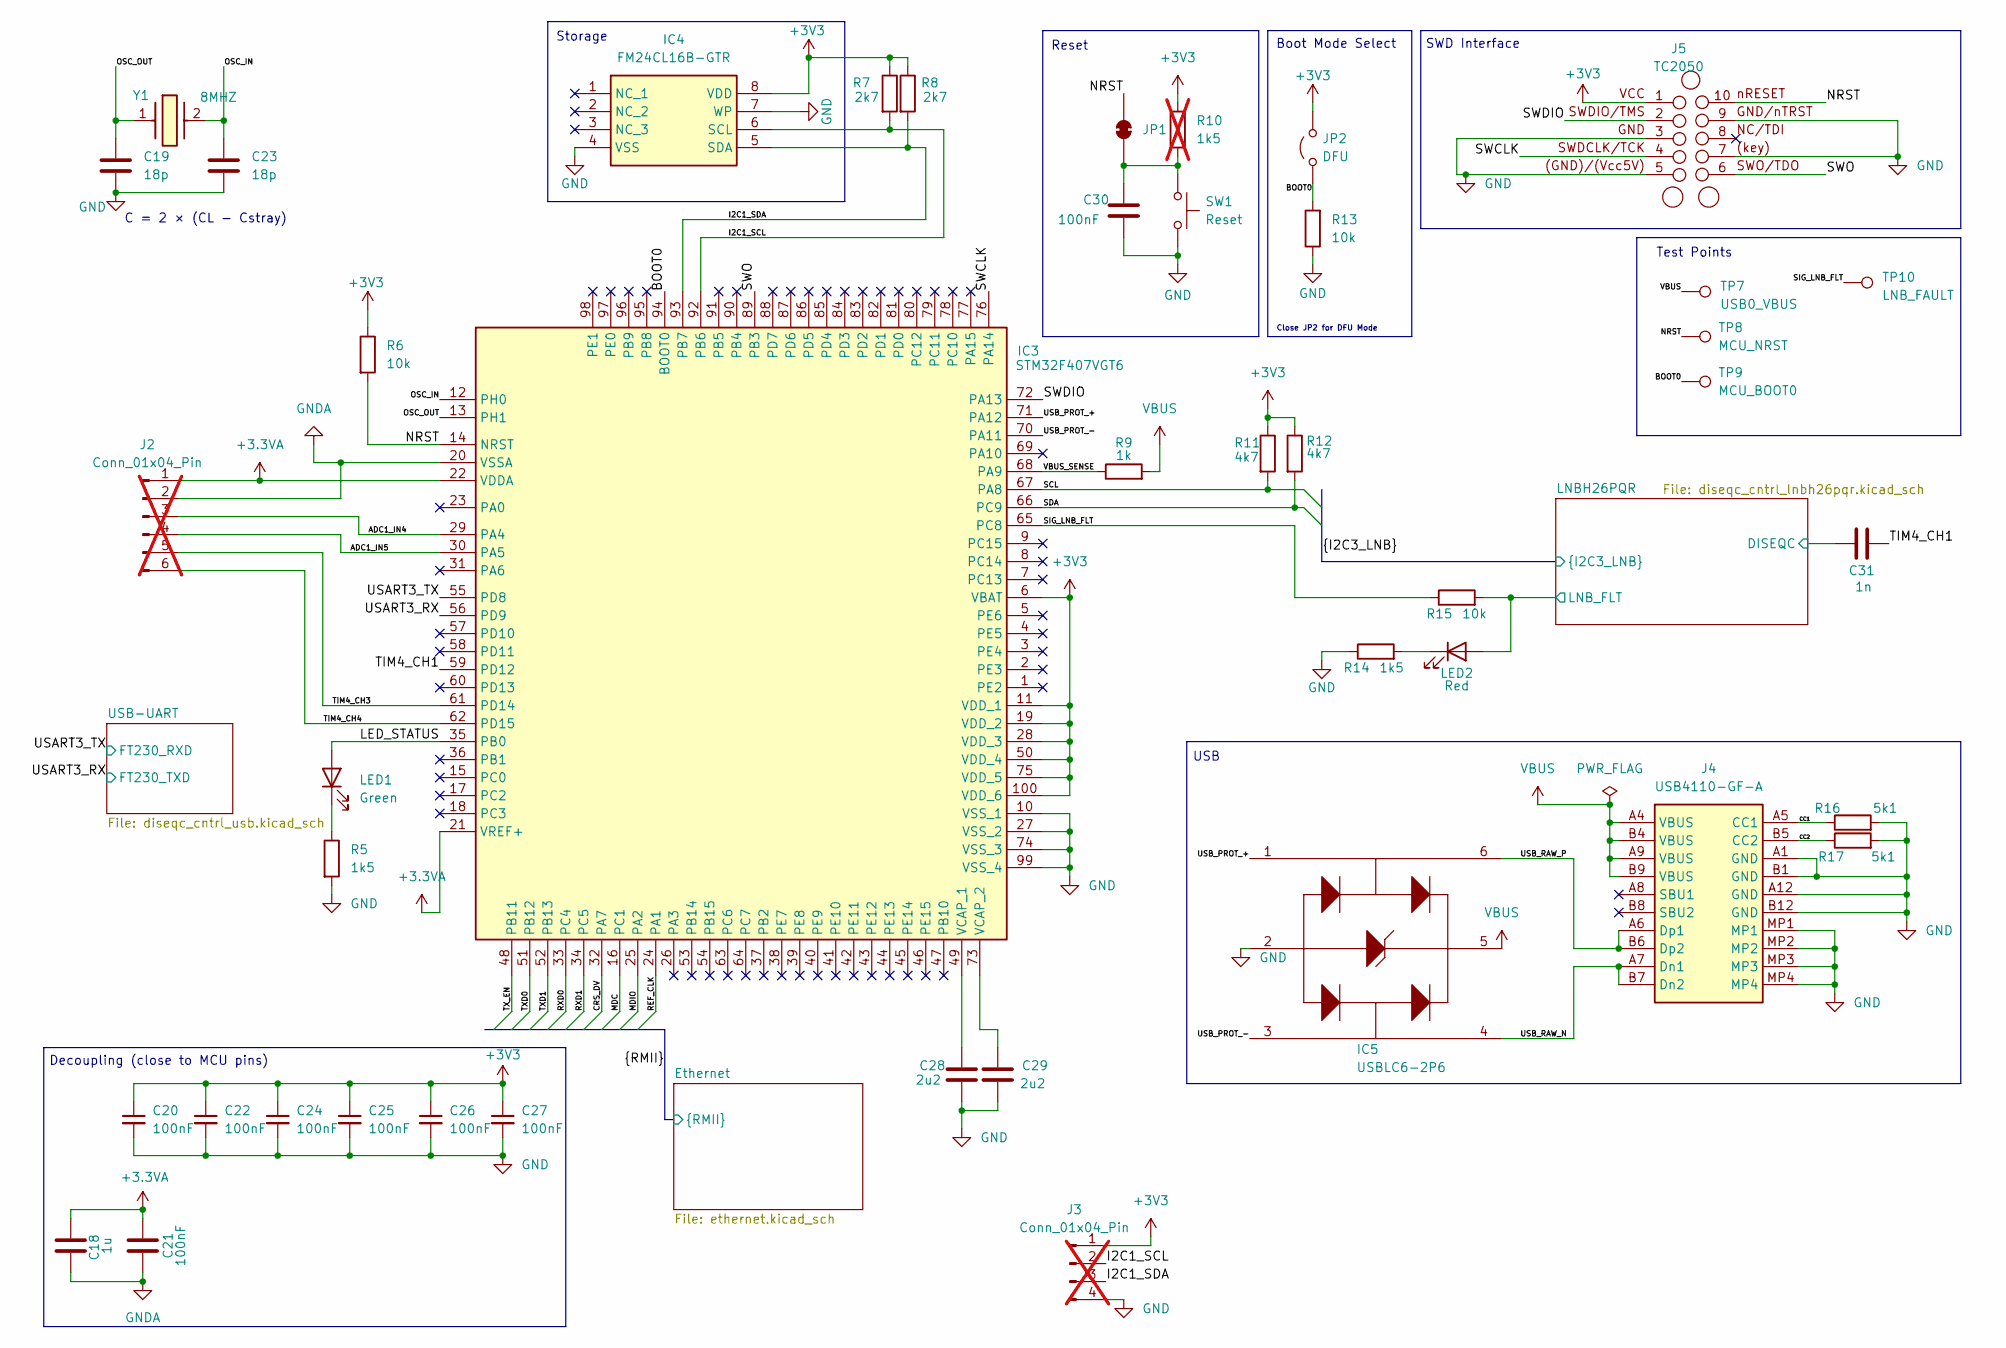
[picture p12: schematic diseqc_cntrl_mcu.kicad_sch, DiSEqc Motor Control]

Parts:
C18: 1u; C_0603_1608Metric; Mouser Part Number 81-GRM39R105K10
C19, C23: 18p; C_0603_1608Metric; Manufacturer_Part_Number 600S180JT250XT; Mouser Part Number 581-06031A180CAT2A
C20, C21, C22, C24, C25, C26, C27, C30: 100nF; C_0603_1608Metric
C28, C29: 2u2; C_0603_1608Metric; Mouser Part Number 81-GRM188R6YA225MA2D
C31: 1n; C_0603_1608Metric; Mouser Part Number 81-GRM39X102K050
IC3: STM32F407VGT6; QFP50P1600X1600X160-100N; Mouser Part Number 511-STM32F407VGT6
IC4: FM24CL16B-GTR; SOIC127P602X173-8N; Mouser Part Number 877-FM24CL16B-GTR
IC5: USBLC6-2P6; USBLC62P6; Mouser Part Number 511-USBLC6-2P6
J2: Conn_01x04_Pin; PinHeader_2x03_P2.54mm_Vertical_SMD; Mouser Part Number 200-TMM10501TSSM; not fitted
J3: Conn_01x04_Pin; PinHeader_1x04_P2.00mm_Vertical_SMD_Pin1Left; Mouser Part Number 200-TMM10501TSSM; not fitted
J4: USB4110-GF-A; USB4110GFA; Mouser Part Number 640-USB4110-GF-A
J5: TC2050; Tag-Connect_TC2050-IDC-FP_2x05_P1.27mm_Vertical
JP1: SolderJumper_2_Bridged; SolderJumper-2_P1.3mm_Bridged_Pad1.0x1.5mm
JP2: DFU; PinHeader_1x02_P2.54mm_Vertical
LED1: Green; LED_0603_1608Metric; Mouser Part Number 604-APG1608ZGC
LED2: Red; LED_0603_1608Metric
R5: 1k5; R_0603_1608Metric; Mouser Part Number 603-AC0603JR-071K5L
R6, R15: 10k; R_0603_1608Metric
R7, R8: 2k7; R_0603_1608Metric; Mouser Part Number 603-AR0603JR-072K7L
R9: 1k; R_0603_1608Metric; Tolerance 5%
R10: 1k5; R_0603_1608Metric; not fitted
R11, R12: 4k7; R_0603_1608Metric; Mouser Part Number 603-AC0603FR-074K7L
R13: 10k; R_0603_1608Metric; Mouser Part Number 603-RC0603DR-0710KL
R14: 1k5; R_0603_1608Metric
R16, R17: 5k1; R_0603_1608Metric; Mouser Part Number 603-RC0603FR-075K1P
SW1: Reset; 95C04B3GWRT
TP7: USB0_VBUS; TestPoint_THTPad_D1.0mm_Drill0.5mm_annotated
TP8: MCU_NRST; TestPoint_THTPad_D1.0mm_Drill0.5mm_annotated
TP9: MCU_BOOT0; TestPoint_THTPad_D1.0mm_Drill0.5mm_annotated
TP10: LNB_FAULT; TestPoint_THTPad_D1.0mm_Drill0.5mm_annotated
Y1: 8MHZ; ABLS8000MHz20B3HT; Mouser Part Number 815-LS8000MHZ20B3HT

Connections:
+3.3VA: C18.1, C21.2, IC3.21 (VREF+), IC3.22 (VDDA), J2.1; also elsewhere on the board
+3V3: C20.1, C22.1, C24.1, C25.1, C26.1, C27.1, IC3.6 (VBAT), IC3.11 (VDD_1), IC3.19 (VDD_2), IC3.28 (VDD_3), IC3.50 (VDD_4), IC3.75 (VDD_5), IC3.100 (VDD_6), IC4.8 (VDD), J3.1, J5.1 (VCC), JP2.2 (B), R6.1, R7.1, R8.1, R10.1, R11.1, R12.1; also elsewhere on the board
/MCU/ADC1_IN4: IC3.29 (PA4), J2.3
/MCU/ADC1_IN5: IC3.30 (PA5), J2.4
/MCU/BOOT0: IC3.94 (BOOT0), JP2.1 (A), R13.2, TP9.1 (1_1)
/MCU/CC1: J4.A5 (CC1), R16.1
/MCU/CC2: J4.B5 (CC2), R17.1
/MCU/CRS_DV: IC3.32 (PA7); also elsewhere on the board
/MCU/I2C1_SCL: IC3.92 (PB6), IC4.6 (SCL), J3.2, R7.2
/MCU/I2C1_SDA: IC3.93 (PB7), IC4.5 (SDA), J3.3, R8.2
/MCU/LED_STATUS: IC3.35 (PB0), LED1.2 (A)
/MCU/LNBH26PQR/DISEQC: C31.1; also elsewhere on the board
/MCU/LNBH26PQR/LNB_FLT: LED2.2 (A), R15.2; also elsewhere on the board
/MCU/MDC: IC3.16 (PC1); also elsewhere on the board
/MCU/MDIO: IC3.25 (PA2); also elsewhere on the board
/MCU/NRST: IC3.14 (NRST), J5.10 (nRESET), JP1.2 (B), R6.2, TP8.1 (1_1); also elsewhere on the board
/MCU/OSC_IN: C23.1, IC3.12 (PH0), Y1.2
/MCU/OSC_OUT: C19.1, IC3.13 (PH1), Y1.1
/MCU/REF_CLK: IC3.24 (PA1); also elsewhere on the board
/MCU/RXD0: IC3.33 (PC4); also elsewhere on the board
/MCU/RXD1: IC3.34 (PC5); also elsewhere on the board
/MCU/SCL: IC3.67 (PA8), R11.2; also elsewhere on the board
/MCU/SDA: IC3.66 (PC9), R12.2; also elsewhere on the board
/MCU/SIG_LNB_FLT: IC3.65 (PC8), R15.1, TP10.1 (1_1)
/MCU/SWCLK: IC3.76 (PA14), J5.4 (SWDCLK/TCK)
/MCU/SWDIO: IC3.72 (PA13), J5.2 (SWDIO/TMS)
/MCU/SWO: IC3.89 (PB3), J5.6 (SWO/TDO)
/MCU/TIM4_CH1: C31.2, IC3.59 (PD12)
/MCU/TIM4_CH3: IC3.61 (PD14), J2.5
/MCU/TIM4_CH4: IC3.62 (PD15), J2.6
/MCU/TXD0: IC3.51 (PB12); also elsewhere on the board
/MCU/TXD1: IC3.52 (PB13); also elsewhere on the board
/MCU/TX_EN: IC3.48 (PB11); also elsewhere on the board
/MCU/USART3_RX: IC3.56 (PD9); also elsewhere on the board
/MCU/USART3_TX: IC3.55 (PD8); also elsewhere on the board
/MCU/USB_PROT_+: IC3.71 (PA12), IC5.1 (I/O1_1)
/MCU/USB_PROT_-: IC3.70 (PA11), IC5.3 (I/O2_1)
/MCU/USB_RAW_N: IC5.4 (I/O2_2), J4.A7 (Dn1), J4.B7 (Dn2)
/MCU/USB_RAW_P: IC5.6 (I/O1_2), J4.A6 (Dp1), J4.B6 (Dp2)
/MCU/VBUS_SENSE: IC3.68 (PA9), R9.1
GND: C19.2, C20.2, C22.2, C23.2, C24.2, C25.2, C26.2, C27.2, C28.2, C29.1, C30.2, IC3.10 (VSS_1), IC3.27 (VSS_2), IC3.74 (VSS_3), IC3.99 (VSS_4), IC4.4 (VSS), IC4.7 (WP), IC5.2 (GND), J3.4, J4.A1 (GND), J4.A12 (GND), J4.B1 (GND), J4.B12 (GND), J4.MP1, J4.MP2, J4.MP3, J4.MP4, J5.3 (GND), J5.5 ((GND)/(Vcc5V)), J5.7 ((key)), J5.9 (GND/nTRST), R5.2, R13.1, R14.1, R16.2, R17.2, SW1.T2; also elsewhere on the board
GNDA: C18.2, C21.1, IC3.20 (VSSA), J2.2; also elsewhere on the board
unnamed: C28.1, IC3.49 (VCAP_1)
unnamed: C29.2, IC3.73 (VCAP_2)
unnamed: C30.1, JP1.1 (A), R10.2, SW1.T1
unnamed: LED1.1 (K), R5.1
unnamed: LED2.1 (K), R14.2
VBUS: IC5.5 (VBUS), J4.A4 (VBUS), J4.A9 (VBUS), J4.B4 (VBUS), J4.B9 (VBUS), R9.2, TP7.1 (1_1)

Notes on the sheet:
C = 2 × (CL - Cstray)
Reset
Close JP2 for DFU Mode
Storage
SWD Interface
USB
Boot Mode Select
Decoupling (close to MCU pins)
Test Points

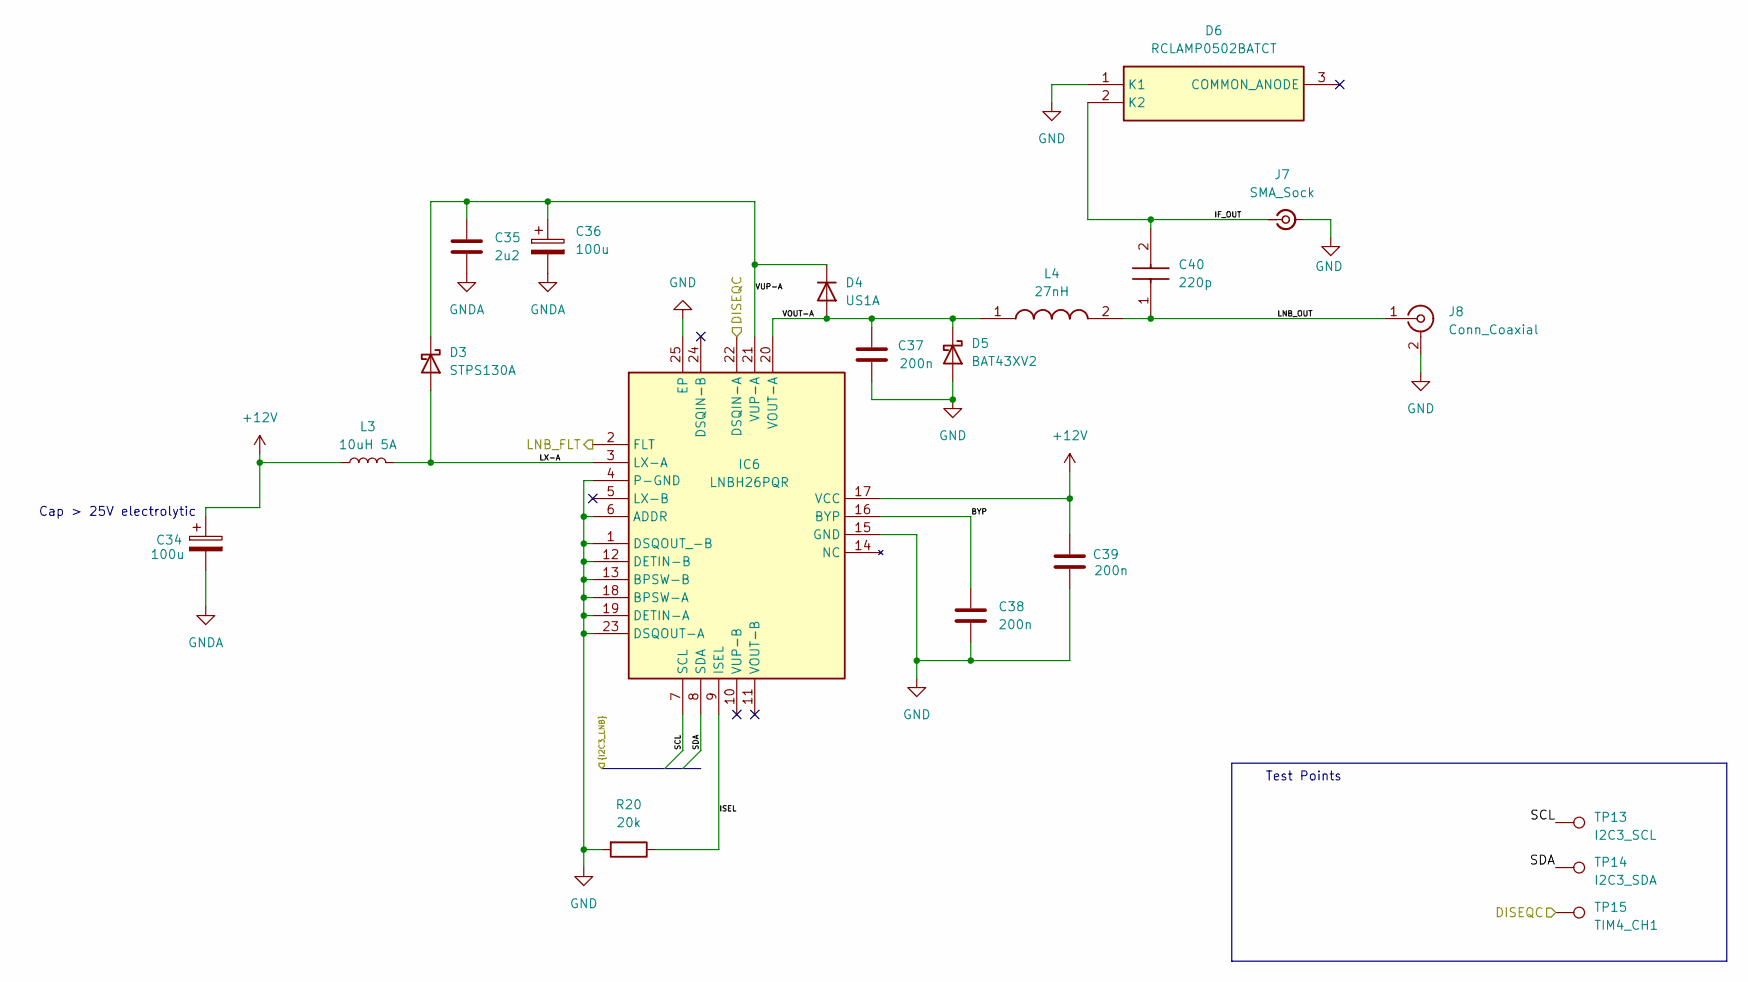
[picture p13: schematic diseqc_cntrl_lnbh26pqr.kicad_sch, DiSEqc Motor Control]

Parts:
C34, C36: 100u; CAPAE660X770N; Mouser Part Number 710-865080445010
C35: 2u2; C_0603_1608Metric; Mouser Part Number 81-GRM188R6YA225MA2D
C37, C38, C39: 200n; C_0603_1608Metric; Mouser Part Number 791-0603B204K160CT
C40: 220p; C_0603_1608Metric; Mouser Part Number 81-GRM185C2A221JA01D
D3: STPS130A; STTH2R02AY; Mouser Part Number 511-STPS130A
D4: US1A; D_SMA; Mouser Part Number 637-US1A
D5: BAT43XV2; SODFL1608X70N; Mouser Part Number 512-BAT43XV2
D6: RCLAMP0502BATCT; SOT50P160X90-3N; Mouser Part Number 947-RCLAMP0502BATCT
IC6: LNBH26PQR; QFN50P400X400X100-25N-D; Manufacturer_Part_Number LNBH26PQR; Mouser Part Number 511-LNBH26PQR
J7: SMA_Sock; SMA_Molex_73251-1153_EdgeMount_Horizontal; Mouser Part Number 538-73251-1153
J8: Conn_Coaxial; AMPHENOL_531-40156; Maufacturer_Part_Number 531-40156; Mouser Part Number 523-531-40156
L3: 10uH 5A; SRP6060FA4R7M
L4: 27nH; 0603DC27NXJRW; Mouser Part Number 994-0603DC-27NXJRW
R20: 20k; R_0603_1608Metric; Tolerance 1%; Mouser Part Number 603-RC0603JR-07100KL
TP13: I2C3_SCL; TestPoint_THTPad_D1.0mm_Drill0.5mm_annotated
TP14: I2C3_SDA; TestPoint_THTPad_D1.0mm_Drill0.5mm_annotated
TP15: TIM4_CH1; TestPoint_THTPad_D1.0mm_Drill0.5mm_annotated

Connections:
+12V: C34.1, C39.2, IC6.17 (VCC), L3.1; also elsewhere on the board
/MCU/LNBH26PQR/BYP: C38.2, IC6.16 (BYP)
/MCU/LNBH26PQR/DISEQC: IC6.22 (DSQIN-A), TP15.1 (1_1); also elsewhere on the board
/MCU/LNBH26PQR/IF_OUT: C40.2, D6.2 (K2), J7.1 (In)
/MCU/LNBH26PQR/ISEL: IC6.9 (ISEL), R20.1
/MCU/LNBH26PQR/LNB_FLT: IC6.2 (FLT); also elsewhere on the board
/MCU/LNBH26PQR/LNB_OUT: C40.1, J8.1 (In), L4.2
/MCU/LNBH26PQR/LX-A: D3.2 (A), IC6.3 (LX-A), L3.2
/MCU/LNBH26PQR/VOUT-A: C37.1, D4.2 (A), D5.1 (K), IC6.20 (VOUT-A), L4.1
/MCU/LNBH26PQR/VUP-A: C35.1, C36.1, D3.1 (K), D4.1 (K), IC6.21 (VUP-A)
/MCU/SCL: IC6.7 (SCL), TP13.1 (1_1); also elsewhere on the board
/MCU/SDA: IC6.8 (SDA), TP14.1 (1_1); also elsewhere on the board
GND: C37.2, C38.1, C39.1, D5.2 (A), D6.1 (K1), IC6.1 (DSQOUT_-B), IC6.4 (P-GND), IC6.6 (ADDR), IC6.12 (DETIN-B), IC6.13 (BPSW-B), IC6.15 (GND), IC6.18 (BPSW-A), IC6.19 (DETIN-A), IC6.23 (DSQOUT-A), IC6.25 (EP), J7.2 (Ext), J8.2 (Ext), R20.2; also elsewhere on the board
GNDA: C34.2, C35.2, C36.2; also elsewhere on the board

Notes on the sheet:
Cap > 25V electrolytic
Test Points

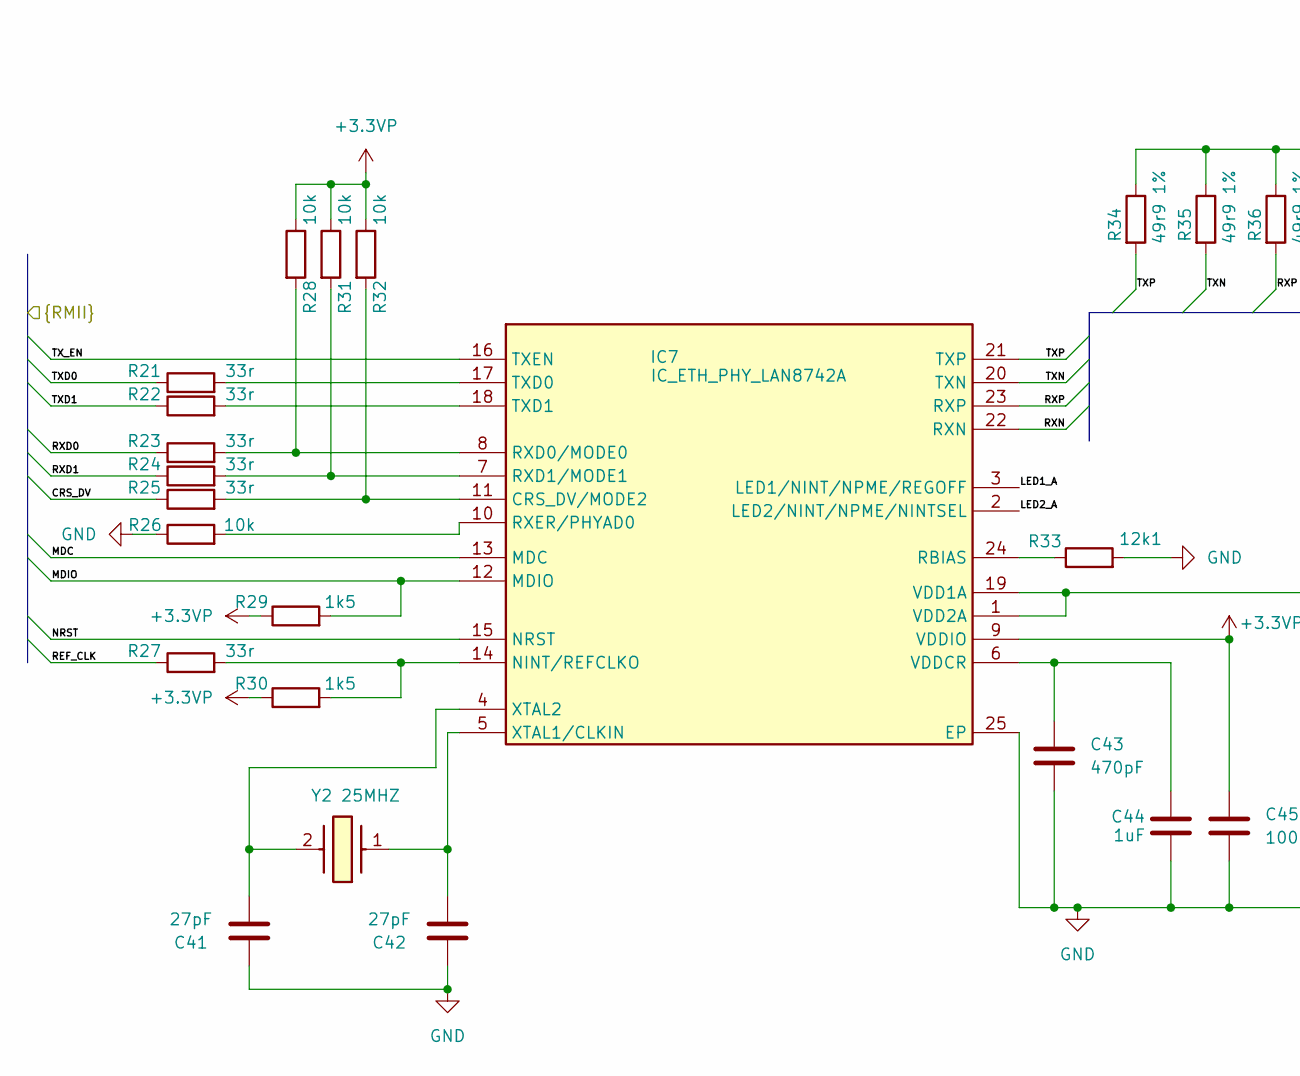
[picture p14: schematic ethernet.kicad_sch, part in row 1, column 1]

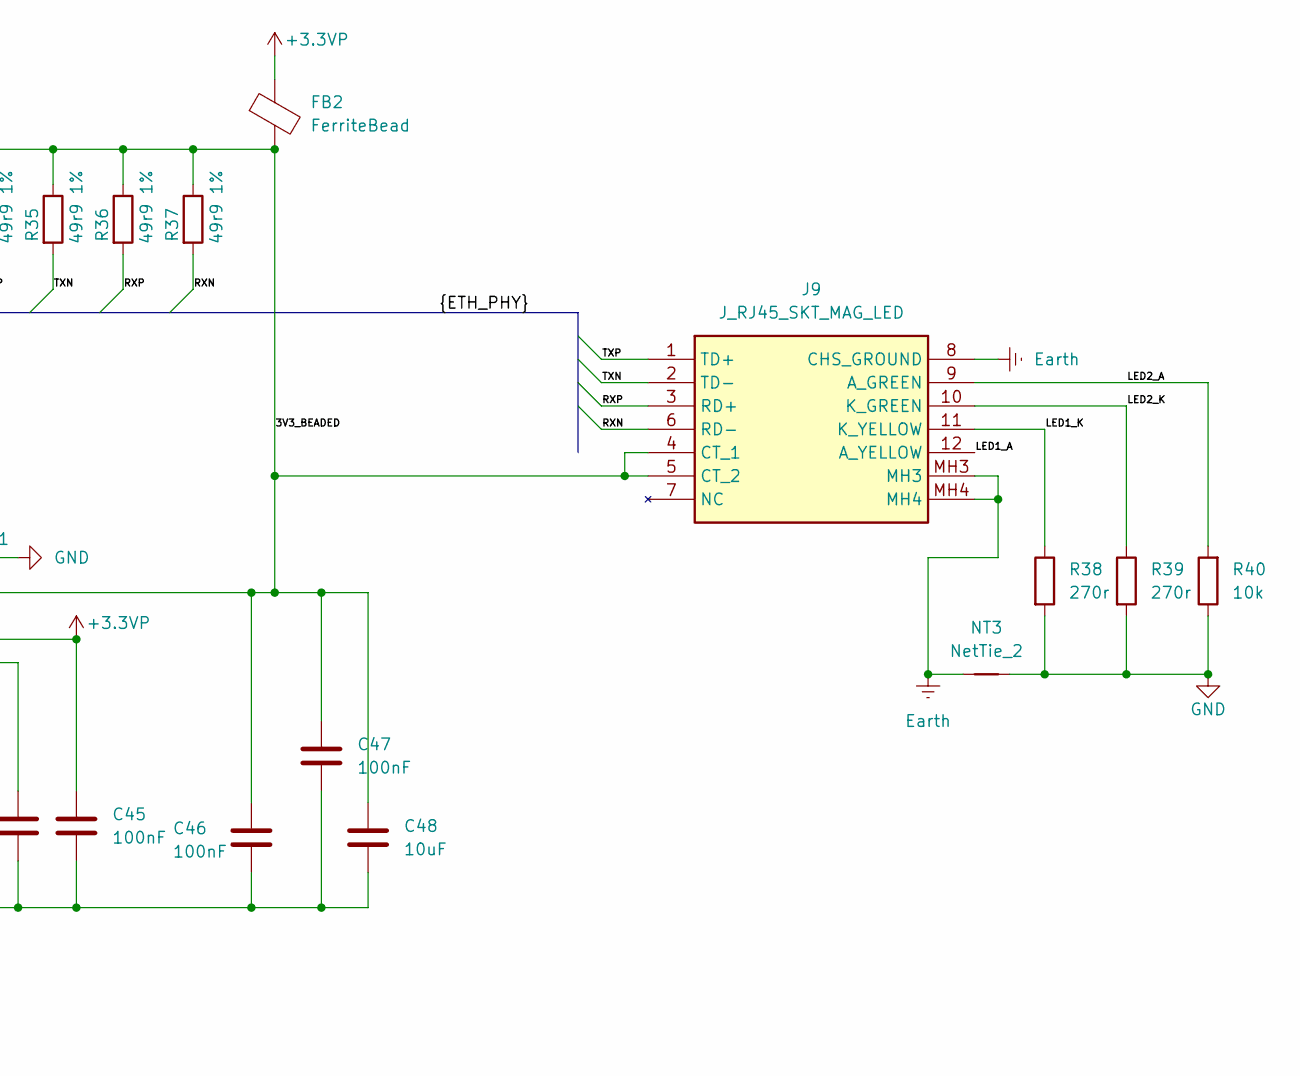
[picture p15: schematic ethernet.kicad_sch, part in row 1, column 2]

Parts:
C41, C42: 27pF; C_0603_1608Metric; Tolerance 5%
C43: 470pF; C_0603_1608Metric
C44: 1uF; C_0603_1608Metric
C45, C46, C47: 100nF; C_0603_1608Metric
C48: 10uF; C_0603_1608Metric
FB2: FerriteBead; L_0603_1608Metric
IC7: IC_ETH_PHY_LAN8742A; VQFN-24-1EP_4x4mm_P0.5mm_EP2.5x2.5mm_ThermalVias; Mouser Part Number 579-LAN8742A-CZ-TR
J9: J_RJ45_SKT_MAG_LED; J0011D21BNL; Mouser Part Number 673-J0011D21BNL
NT3: NetTie_2; NetTie-2_SMD_Pad2.0mm
R21, R22, R23, R24, R25, R27: 33r; R_0603_1608Metric
R26, R28, R31, R32, R40: 10k; R_0603_1608Metric
R29, R30: 1k5; R_0603_1608Metric
R33: 12k1; R_0603_1608Metric
R34, R35, R36, R37: 49r9 1%; R_0603_1608Metric; Tolerance 1%
R38, R39: 270r; R_0603_1608Metric; Tolerance 5%
Y2: 25MHZ; ABLS25000MHZDFT; Mouser Part Number 815-ABLS25.MHZDFT

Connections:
+3.3VP: C45.1, FB2.1, IC7.9 (VDDIO), R28.1, R29.1, R30.1, R31.1, R32.1; also elsewhere on the board
/MCU/CRS_DV: R25.1; also elsewhere on the board
/MCU/Ethernet/3V3_BEADED: C46.1, C47.1, C48.1, FB2.2, IC7.1 (VDD2A), IC7.19 (VDD1A), J9.4 (CT_1), J9.5 (CT_2), R34.1, R35.1, R36.1, R37.1
/MCU/Ethernet/LED1_A: IC7.3 (LED1/NINT/NPME/REGOFF), J9.12 (A_YELLOW)
/MCU/Ethernet/LED1_K: J9.11 (K_YELLOW), R38.1
/MCU/Ethernet/LED2_A: IC7.2 (LED2/NINT/NPME/NINTSEL), J9.9 (A_GREEN), R40.2
/MCU/Ethernet/LED2_K: J9.10 (K_GREEN), R39.1
/MCU/Ethernet/RXN: IC7.22 (RXN), J9.6 (RD-), R37.2
/MCU/Ethernet/RXP: IC7.23 (RXP), J9.3 (RD+), R36.2
/MCU/Ethernet/TXN: IC7.20 (TXN), J9.2 (TD-), R35.2
/MCU/Ethernet/TXP: IC7.21 (TXP), J9.1 (TD+), R34.2
/MCU/MDC: IC7.13 (MDC); also elsewhere on the board
/MCU/MDIO: IC7.12 (MDIO), R29.2; also elsewhere on the board
/MCU/NRST: IC7.15 (NRST); also elsewhere on the board
/MCU/REF_CLK: R27.1; also elsewhere on the board
/MCU/RXD0: R23.1; also elsewhere on the board
/MCU/RXD1: R24.1; also elsewhere on the board
/MCU/TXD0: R21.1; also elsewhere on the board
/MCU/TXD1: R22.1; also elsewhere on the board
/MCU/TX_EN: IC7.16 (TXEN); also elsewhere on the board
Earth: J9.8 (CHS_GROUND), J9.MH3, J9.MH4, NT3.1
GND: C41.1, C42.1, C43.2, C44.2, C45.2, C46.2, C47.2, C48.2, IC7.25 (EP), NT3.2, R26.1, R33.2, R38.2, R39.2, R40.1; also elsewhere on the board
unnamed: IC7.11 (CRS_DV/MODE2), R25.2, R32.2
unnamed: IC7.14 (NINT/REFCLKO), R27.2, R30.2
unnamed: IC7.24 (RBIAS), R33.1
unnamed: IC7.8 (RXD0/MODE0), R23.2, R28.2
unnamed: IC7.7 (RXD1/MODE1), R24.2, R31.2
unnamed: IC7.10 (RXER/PHYAD0), R26.2
unnamed: IC7.17 (TXD0), R21.2
unnamed: IC7.18 (TXD1), R22.2
unnamed: C43.1, C44.1, IC7.6 (VDDCR)
unnamed: C42.2, IC7.5 (XTAL1/CLKIN), Y2.1
unnamed: C41.2, IC7.4 (XTAL2), Y2.2

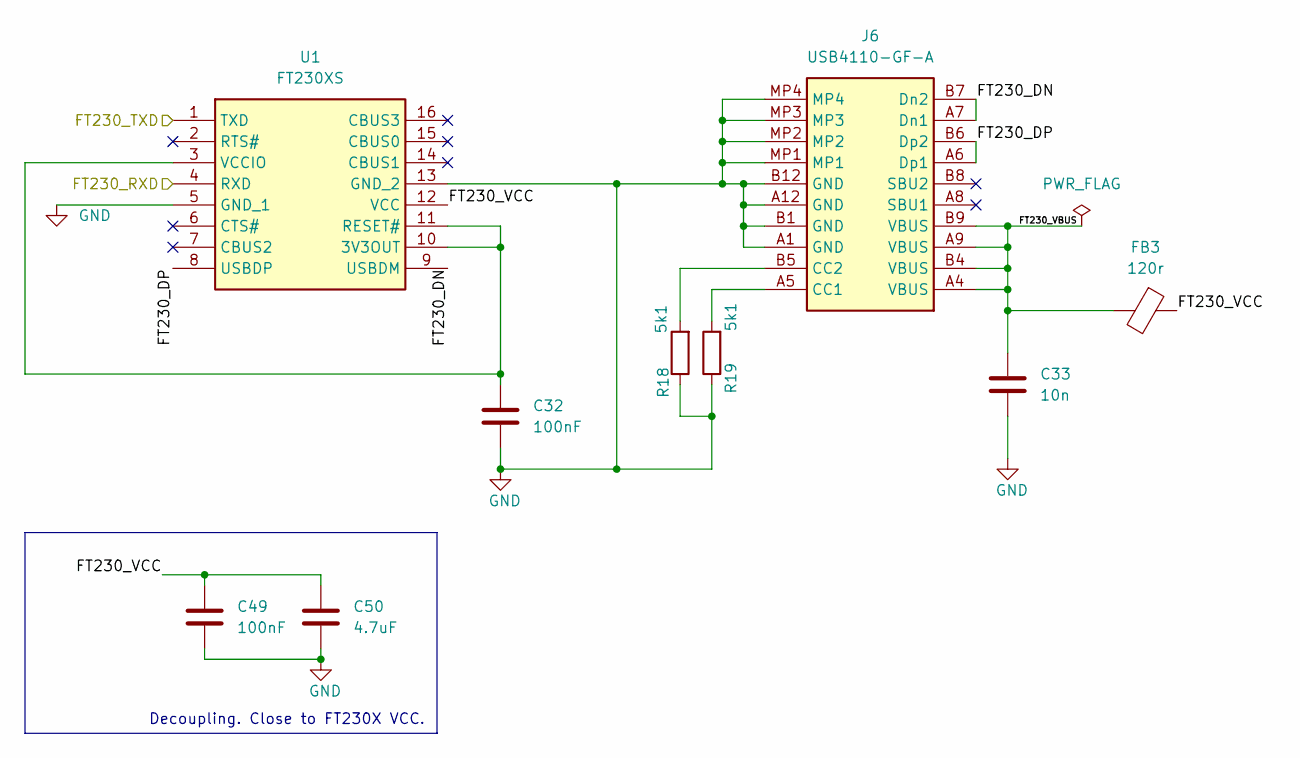
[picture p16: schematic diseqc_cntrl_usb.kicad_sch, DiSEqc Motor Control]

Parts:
C32, C49: 100nF; C_0603_1608Metric
C33: 10n; C_0603_1608Metric
C50: 4.7uF; C_0805_2012Metric
FB3: 120r; L_0603_1608Metric
J6: USB4110-GF-A; USB4110GFA; Mouser Part Number 640-USB4110-GF-A
R18, R19: 5k1; R_0603_1608Metric; Mouser Part Number 603-RC0603FR-075K1P
U1: FT230XS; SOP64P599X175-16N; Mouser Part Number 895-FT230XS-U

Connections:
/MCU/USART3_RX: U1.1 (TXD); also elsewhere on the board
/MCU/USART3_TX: U1.4 (RXD); also elsewhere on the board
/MCU/USB-UART/FT230_DN: J6.A7 (Dn1), J6.B7 (Dn2), U1.9 (USBDM)
/MCU/USB-UART/FT230_DP: J6.A6 (Dp1), J6.B6 (Dp2), U1.8 (USBDP)
/MCU/USB-UART/FT230_VBUS: C33.1, FB3.2, J6.A4 (VBUS), J6.A9 (VBUS), J6.B4 (VBUS), J6.B9 (VBUS)
/MCU/USB-UART/FT230_VCC: C49.1, C50.2, FB3.1, U1.12 (VCC)
GND: C32.2, C33.2, C49.2, C50.1, J6.A1 (GND), J6.A12 (GND), J6.B1 (GND), J6.B12 (GND), J6.MP1, J6.MP2, J6.MP3, J6.MP4, R18.1, R19.1, U1.5 (GND_1), U1.13 (GND_2); also elsewhere on the board
unnamed: J6.A5 (CC1), R19.2
unnamed: J6.B5 (CC2), R18.2
unnamed: C32.1, U1.3 (VCCIO), U1.10 (3V3OUT), U1.11 (RESET#)

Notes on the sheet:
Decoupling. Close to FT230X VCC.

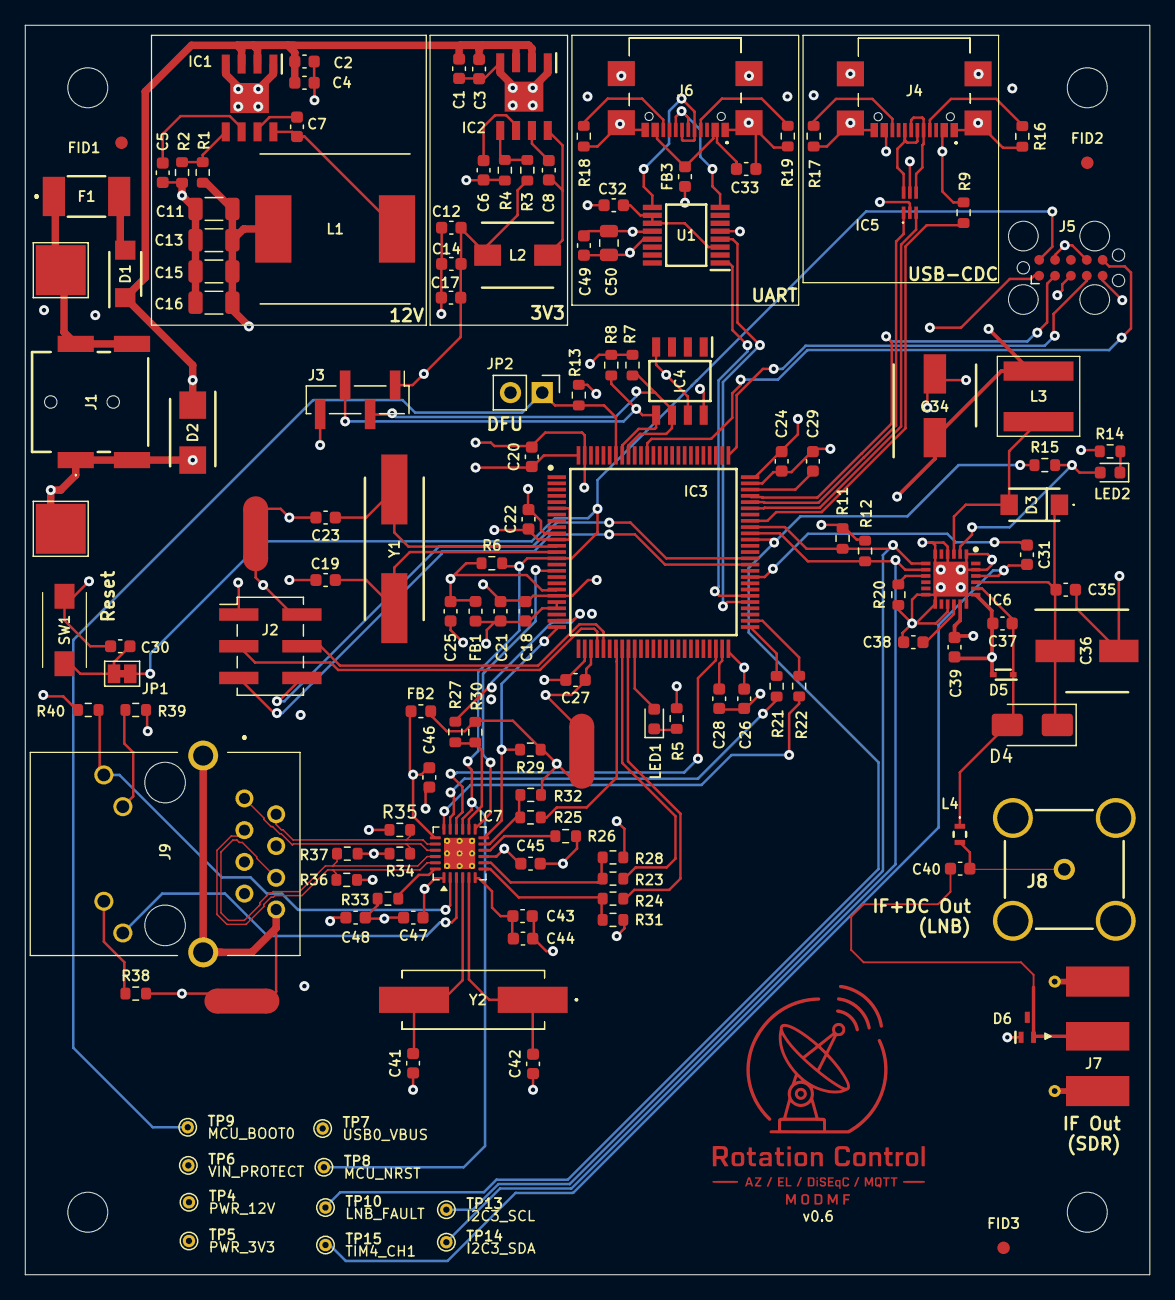
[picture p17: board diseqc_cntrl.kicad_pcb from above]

Board: 4 copper layers, 90.0 x 100.0 mm, 147 parts (0 on the bottom side), 96 nets.

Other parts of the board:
MOUNT01, MOUNT02, MOUNT03, MOUNT04: MountingHole_3.2mm_M3

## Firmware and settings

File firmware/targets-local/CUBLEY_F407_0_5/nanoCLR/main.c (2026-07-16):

//
// Copyright (c) .NET Foundation and Contributors
// See LICENSE file in the project root for full license information.
//
// CUBLEY_F407_0_5 nanoCLR entry point — ultra-minimal baseline.
//
// Responsibilities:
//   * Initialise ChibiOS HAL and clock tree.
//   * Configure USART3 (PD8 TX / PD9 RX, AF7) at 921600 as the wire-protocol
//     transport. This is the same transport nanoBooter used, so the host
//     debugger stays connected across the booter → CLR handoff.
//   * Spin up ReceiverThread (wire protocol) and CLRStartupThread.
//
// Everything else (CRC, RNG, watchdog, USB CDC, board diagnostics, LED
// heartbeat) is deliberately out of scope for Phase 0. It is added back in
// later phases as bring-up requires it.

#include <ch.h>
#include <hal.h>
#include <cmsis_os.h>
#include <string.h>

#include <serialcfg.h>
#if (HAL_USE_SERIAL_USB == TRUE)
#include "../common/usbcfg.h"
#endif
#include <CLR_Startup_Thread.h>
#include <WireProtocol_ReceiverThread.h>
#include <nanoCLR_Application.h>
#include <nanoHAL_v2.h>
#include "fram_native.h"
#include "lnbh26_native.h"

static void FramSelfTestThread(void const *argument);
static void LnbSelfTestThread(void const *argument);

osThreadDef(ReceiverThread,     osPriorityHigh,   2048, "ReceiverThread");
osThreadDef(CLRStartupThread,   osPriorityNormal, 4096, "CLRStartupThread");
osThreadDef(FramSelfTestThread, osPriorityBelowNormal, 1024, "FramSelfTestThread");
osThreadDef(LnbSelfTestThread,  osPriorityBelowNormal, 1024, "LnbSelfTestThread");

#if (HAL_USE_SERIAL_USB == TRUE)
static THD_WORKING_AREA(waUsbCdcInitThread, 768);
static THD_FUNCTION(UsbCdcInitThread, arg)
{
    (void)arg;
    chRegSetThreadName("USB_CDC_Init");

    sduObjectInit(&SDU1);
    sduStart(&SDU1, &serusbcfg);

    usbDisconnectBus(serusbcfg.usbp);
    chThdSleepMilliseconds(100);
    usbStart(serusbcfg.usbp, &usbcfg);
    usbConnectBus(serusbcfg.usbp);

    chThdExit(MSG_OK);
}
#endif

volatile uint32_t g_fram_native_selftest_thread_marker = 0;
volatile uint32_t g_fram_native_selftest_status = 0;
volatile uint32_t g_fram_native_selftest_i2c = 0;

volatile uint32_t g_lnb_native_selftest_thread_marker = 0;
volatile uint32_t g_lnb_native_selftest_status = 0;
volatile uint32_t g_lnb_native_selftest_i2c = 0;
volatile uint32_t g_lnb_native_selftest_status1 = 0;

static void RunFramNativeSelfTest(void)
{
    fram_handle_t *hfram = fram_get_global_handle();
    static const uint8_t pattern[] = {0x46, 0x52, 0x41, 0x4D, 0x4E, 0x41, 0x54, 0x01};
    uint8_t readBack[sizeof(pattern)] = {0};

    // Format: 0xF4SSCCDD
    g_fram_native_selftest_status = 0xF4000001u;

    fram_status_t initStatus = fram_init(hfram, &I2CD1, 0x50);
    g_fram_native_selftest_i2c = (uint32_t)(fram_get_last_i2c_msg() & 0xFFFF);
    if (initStatus != FRAM_OK)
    {
        g_fram_native_selftest_status = 0xF4010000u | ((uint32_t)initStatus & 0xFFu);
        return;
    }

    fram_status_t writeStatus = fram_write(hfram, 0x0100, pattern, (uint16_t)sizeof(pattern));
    g_fram_native_selftest_i2c = (uint32_t)(fram_get_last_i2c_msg() & 0xFFFF);
    if (writeStatus != FRAM_OK)
    {
        g_fram_native_selftest_status = 0xF4020000u | ((uint32_t)writeStatus & 0xFFu);
        return;
    }

    fram_status_t readStatus = fram_read(hfram, 0x0100, readBack, (uint16_t)sizeof(readBack));
    g_fram_native_selftest_i2c = (uint32_t)(fram_get_last_i2c_msg() & 0xFFFF);
    if (readStatus != FRAM_OK)
    {
        g_fram_native_selftest_status = 0xF4030000u | ((uint32_t)readStatus & 0xFFu);
        return;
    }

    if (memcmp(pattern, readBack, sizeof(pattern)) != 0)
    {
        g_fram_native_selftest_status = 0xF4040001u;
        return;
    }

    static const uint8_t clearBuf[sizeof(pattern)] = {0};
    (void)fram_write(hfram, 0x0100, clearBuf, (uint16_t)sizeof(clearBuf));
    g_fram_native_selftest_i2c = (uint32_t)(fram_get_last_i2c_msg() & 0xFFFF);
    g_fram_native_selftest_status = 0xF4FF0001u;
}

static void FramSelfTestThread(void const *argument)
{
    (void)argument;
    g_fram_native_selftest_thread_marker = 0xF4AA0001u;

    chThdSleepMilliseconds(3000);
    g_fram_native_selftest_thread_marker = 0xF4AA0002u;

    RunFramNativeSelfTest();
    g_fram_native_selftest_thread_marker = 0xF4AA00FFu;

    while (true)
    {
        osDelay(1000);
    }
}

static void RunLnbNativeSelfTest(void)
{
    int32_t statusReg = 0;

    // Format: 0xB2SSCCDD
    g_lnb_native_selftest_status = 0xB2000001u;

    int32_t initStatus = lnb_native_init();
    g_lnb_native_selftest_i2c = (uint32_t)(lnb_get_last_i2c_msg() & 0xFFFF);
    if (initStatus != (int32_t)LNB_OK)
    {
        g_lnb_native_selftest_status = 0xB2010000u | ((uint32_t)initStatus & 0xFFu);
        return;
    }

    int32_t polarizationStatus = lnb_native_set_polarization((int32_t)LNB_NATIVE_POLARIZATION_VERTICAL);
    g_lnb_native_selftest_i2c = (uint32_t)(lnb_get_last_i2c_msg() & 0xFFFF);
    if (polarizationStatus != (int32_t)LNB_OK)
    {
        g_lnb_native_selftest_status = 0xB2020000u | ((uint32_t)polarizationStatus & 0xFFu);
        return;
    }

    int32_t bandStatus = lnb_native_set_band((int32_t)LNB_NATIVE_BAND_LOW);
    g_lnb_native_selftest_i2c = (uint32_t)(lnb_get_last_i2c_msg() & 0xFFFF);
    if (bandStatus != (int32_t)LNB_OK)
    {
        g_lnb_native_selftest_status = 0xB2030000u | ((uint32_t)bandStatus & 0xFFu);
        return;
    }

    int32_t enableStatus = lnb_native_set_enable(1);
    g_lnb_native_selftest_i2c = (uint32_t)(lnb_get_last_i2c_msg() & 0xFFFF);
    if (enableStatus != (int32_t)LNB_OK)
    {
        g_lnb_native_selftest_status = 0xB2040000u | ((uint32_t)enableStatus & 0xFFu);
        return;
    }

    int32_t readStatus = lnb_native_read_status(&statusReg);
    g_lnb_native_selftest_i2c = (uint32_t)(lnb_get_last_i2c_msg() & 0xFFFF);
    g_lnb_native_selftest_status1 = (uint32_t)statusReg;
    if (readStatus != (int32_t)LNB_OK)
    {
        g_lnb_native_selftest_status = 0xB2050000u | ((uint32_t)readStatus & 0xFFu);
        return;
    }

    if (lnb_native_get_polarization() != (int32_t)LNB_POL_VERTICAL)
    {
        g_lnb_native_selftest_status = 0xB2060001u;
        return;
    }

    if (lnb_native_get_band() != (int32_t)LNB_BAND_LOW)
    {
        g_lnb_native_selftest_status = 0xB2060002u;
        return;
    }

    (void)lnb_native_set_enable(0);
    g_lnb_native_selftest_i2c = (uint32_t)(lnb_get_last_i2c_msg() & 0xFFFF);
    g_lnb_native_selftest_status = 0xB2FF0001u;
}

static void LnbSelfTestThread(void const *argument)
{
    (void)argument;
    g_lnb_native_selftest_thread_marker = 0xB2AA0001u;

    chThdSleepMilliseconds(3500);
    g_lnb_native_selftest_thread_marker = 0xB2AA0002u;

    RunLnbNativeSelfTest();
    g_lnb_native_selftest_thread_marker = 0xB2AA00FFu;

    while (true)
    {
        osDelay(1000);
    }
}

// USART3 (SD3) wire-protocol configuration.
// CR2 STOP1 bits, no CR1 or CR3 overrides.
static const SerialConfig cubley_wp_serial_cfg = {
    921600,
    0,
    USART_CR2_STOP1_BITS,
    0
};

int main(void)
{
    halInit();
    InitBootClipboard();
    osKernelInitialize();
    Watchdog_Init();

    // Bring up USART3 pins (PD8 = TX AF7, PD9 = RX AF7) and start SD3.
    // board.h leaves these as INPUT+PULLUP for Phase 0; the wire-protocol
    // transport is the earliest consumer, so pins are switched here rather
    // than in board.c PAL init.
    palSetLineMode(PAL_LINE(GPIOD, 8U), PAL_MODE_ALTERNATE(7));
    palSetLineMode(PAL_LINE(GPIOD, 9U), PAL_MODE_ALTERNATE(7));
    sdStart(&SERIAL_DRIVER, &cubley_wp_serial_cfg);

#if (HAL_USE_SERIAL_USB == TRUE)
    // Bring up USB CDC as an independent console channel.
    chThdCreateStatic(
        waUsbCdcInitThread,
        sizeof(waUsbCdcInitThread),
        NORMALPRIO + 2,
        UsbCdcInitThread,
        NULL);
#endif

    // Kick off wire-protocol receiver and CLR startup.
    osThreadCreate(osThread(ReceiverThread), NULL);
    if (osThreadCreate(osThread(FramSelfTestThread), NULL) != NULL)
    {
        g_fram_native_selftest_thread_marker = 0xF4AA0011u;
    }
    else
    {
        g_fram_native_selftest_thread_marker = 0xF4AA00EEu;
    }

    if (osThreadCreate(osThread(LnbSelfTestThread), NULL) != NULL)
    {
        g_lnb_native_selftest_thread_marker = 0xB2AA0011u;
    }
    else
    {
        g_lnb_native_selftest_thread_marker = 0xB2AA00EEu;
    }

    CLR_SETTINGS clrSettings;
    (void)memset(&clrSettings, 0, sizeof(CLR_SETTINGS));
    clrSettings.MaxContextSwitches         = 50;
    clrSettings.WaitForDebugger            = false;
    clrSettings.EnterDebuggerLoopAfterExit = true;

    osThreadCreate(osThread(CLRStartupThread), &clrSettings);
    osKernelStart();

    while (true)
    {
        osDelay(100);
    }
}

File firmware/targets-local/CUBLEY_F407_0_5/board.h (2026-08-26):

/*
    board.h — Cubley v0.5 (STM32F407VGT6, LQFP100)

    Copyright (c) .NET Foundation and Contributors
    See LICENSE.md file in the project root for full license information.

    Structure derived from the ChibiOS ST_STM32F4_DISCOVERY reference board.

    Cubley board pin ownership is documented in
    docs/debug/BOARD_PIN_OWNERSHIP_AUDIT.md. This file names every board-owned
    pin per that audit but starts Phase 0 with all peripheral pins configured
    as safe "input + pull-up". Subsequent phases flip individual pins to their
    alternate functions as each peripheral is brought up:

      Phase 1  PD8/PD9 USART3 (AF7)              wire protocol @ 921600
      Phase 2  PB0 LED_STATUS (output PP low)    boot double-flash
      Phase 3  PB6/PB7 I2C1 (AF4 OD)             FRAM
      Phase 6  PA8/PC9 I2C3 (AF4 OD), PC8 input  LNBH26 + fault
      Phase 7  PA1/PA2/PA7/PB11-13/PC1/PC4/PC5   RMII to LAN8742A (AF11)
      Later    PD12/PD14/PD15 TIM4 (AF2)         DiSEqC carrier, motor
*/

#ifndef BOARD_H
#define BOARD_H

/*===========================================================================*/
/* Driver constants.                                                         */
/*===========================================================================*/

/*
 * Board identifier.
 */
#define BOARD_CUBLEY_F407_0_5
#define BOARD_NAME                  "Cubley v0.5 (STM32F407VG)"
#define BOARD_PHY_ID                MII_LAN8742A_ID
#define BOARD_PHY_RMII

/*
 * Board oscillators-related settings.
 * NOTE: LSE not fitted on Cubley v0.5.
 */
#if !defined(STM32_LSECLK)
#define STM32_LSECLK                0U
#endif

#if !defined(STM32_HSECLK)
#define STM32_HSECLK                8000000U
#endif

/*
 * Board voltages.
 * Required for performance limits calculation.
 */
#define STM32_VDD                   300U

/*
 * MCU type as defined in the ST header.
 */
#undef  STM32F407xx
#define STM32F407xx

/*===========================================================================*/
/* IO pins assignments.                                                      */
/*===========================================================================*/

/* GPIOA: PA1/PA2/PA7 RMII, PA8 I2C3_SCL, PA9 VBUS_SENSE, PA13/PA14 SWD */
#define GPIOA_PIN0                  0U
#define GPIOA_RMII_REF_CLK          1U
#define GPIOA_RMII_MDIO             2U
#define GPIOA_PIN3                  3U
#define GPIOA_PIN4                  4U
#define GPIOA_PIN5                  5U
#define GPIOA_PIN6                  6U
#define GPIOA_RMII_CRS_DV           7U
#define GPIOA_I2C3_SCL              8U
#define GPIOA_PIN9                  9U
#define GPIOA_PIN10                 10U
#define GPIOA_PIN11                 11U
#define GPIOA_PIN12                 12U
#define GPIOA_SWDIO                 13U
#define GPIOA_SWCLK                 14U
#define GPIOA_PIN15                 15U

/* GPIOB: PB0 LED, PB3 SWO, PB6/PB7 I2C1, PB11-PB13 RMII TX */
#define GPIOB_LED_STATUS            0U
#define GPIOB_PIN1                  1U
#define GPIOB_PIN2                  2U
#define GPIOB_SWO                   3U
#define GPIOB_PIN4                  4U
#define GPIOB_PIN5                  5U
#define GPIOB_I2C1_SCL              6U
#define GPIOB_I2C1_SDA              7U
#define GPIOB_PIN8                  8U
#define GPIOB_PIN9                  9U
#define GPIOB_PIN10                 10U
#define GPIOB_RMII_TX_EN            11U
#define GPIOB_RMII_TXD0             12U
#define GPIOB_RMII_TXD1             13U
#define GPIOB_PIN14                 14U
#define GPIOB_PIN15                 15U

/* GPIOC: PC1/PC4/PC5 RMII, PC8 LNB fault, PC9 I2C3_SDA */
#define GPIOC_PIN0                  0U
#define GPIOC_RMII_MDC              1U
#define GPIOC_PIN2                  2U
#define GPIOC_PIN3                  3U
#define GPIOC_RMII_RXD0             4U
#define GPIOC_RMII_RXD1             5U
#define GPIOC_PIN6                  6U
#define GPIOC_PIN7                  7U
#define GPIOC_LNB_FLT               8U
#define GPIOC_I2C3_SDA              9U
#define GPIOC_PIN10                 10U
#define GPIOC_PIN11                 11U
#define GPIOC_PIN12                 12U
#define GPIOC_PIN13                 13U
#define GPIOC_PIN14                 14U
#define GPIOC_PIN15                 15U

/* GPIOD: PD8/PD9 USART3 (wire protocol), PD12/PD14/PD15 TIM4 */
#define GPIOD_PIN0                  0U
#define GPIOD_PIN1                  1U
#define GPIOD_PIN2                  2U
#define GPIOD_PIN3                  3U
#define GPIOD_PIN4                  4U
#define GPIOD_PIN5                  5U
#define GPIOD_PIN6                  6U
#define GPIOD_PIN7                  7U
#define GPIOD_USART3_TX             8U
#define GPIOD_USART3_RX             9U
#define GPIOD_PIN10                 10U
#define GPIOD_PIN11                 11U
#define GPIOD_TIM4_CH1              12U
#define GPIOD_PIN13                 13U
#define GPIOD_TIM4_CH3              14U
#define GPIOD_TIM4_CH4              15U
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

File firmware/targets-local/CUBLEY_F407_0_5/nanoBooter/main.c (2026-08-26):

//
// Copyright (c) .NET Foundation and Contributors
// See LICENSE file in the project root for full license information.
//
// CUBLEY_F407_0_5 nanoBooter entry point — ultra-minimal baseline.
//
// Responsibilities:
//   * Initialise ChibiOS HAL and clock tree.
//   * If a valid nanoCLR image is present in flash, jump to it immediately.
//   * Otherwise stay resident so the host can flash a new CLR image via
//     the wire protocol on USART3 (PD8/PD9 @ 921600).
//   * Blink the status LED (PB0) at 1 Hz so an operator can see the board
//     is stuck in the booter.
//
// Phase 0 has no user-button "hold to stay in booter" gate — Cubley v0.5
// does not have a user button. A future revision may add a UART "hold key"
// or mailbox flag if we ever need one.

#include <ch.h>
#include <hal.h>
#include <cmsis_os.h>

#include <serialcfg.h>
#include <usbcfg.h>
#include <targetHAL.h>
#include <WireProtocol_ReceiverThread.h>
#include <LaunchCLR.h>

osThreadDef(ReceiverThread, osPriorityHigh, 2048, "ReceiverThread");

static THD_WORKING_AREA(waUsbCdcInitThread, 768);
static THD_FUNCTION(UsbCdcInitThread, arg)
{
    (void)arg;
    chRegSetThreadName("USB_CDC_Init");

    sduObjectInit(&SDU1);
    sduStart(&SDU1, &serusbcfg);

    usbDisconnectBus(serusbcfg.usbp);
    chThdSleepMilliseconds(100);
    usbStart(serusbcfg.usbp, &usbcfg);
    usbConnectBus(serusbcfg.usbp);

    chThdExit(MSG_OK);
}

static bool CubleyHasValidClrImageAt(uint32_t imageBase)
{
    const uint32_t initialSp = *((uint32_t *)imageBase);
    const uint32_t resetVector = *((uint32_t *)(imageBase + 4U));
    const uint32_t resetAddress = resetVector & ~1U;

    if (initialSp == 0U || initialSp == 0xFFFFFFFFU)
    {
        return false;
    }

    if ((resetVector & 1U) == 0U)
    {
        return false;
    }

    if (resetAddress < FLASH1_MEMORY_StartAddress ||
        resetAddress >= (FLASH1_MEMORY_StartAddress + FLASH1_MEMORY_Size))
    {
        return false;
    }

    return true;
}

static const SerialConfig cubley_wp_serial_cfg = {
    921600,
    0,
    USART_CR2_STOP1_BITS,
    0
};

int main(void)
{
    halInit();
    InitBootClipboard();
    osKernelInitialize();
    osDelay(20); // let clocks settle before probing flash

    // If flash contains a valid CLR image, launch it.
    if (CubleyHasValidClrImageAt((uint32_t)&__nanoConfig_end__))
    {
        LaunchCLR((uint32_t)&__nanoConfig_end__);
    }

    // No valid CLR — stay in booter and accept updates over USART3.
    palSetLineMode(PAL_LINE(GPIOD, 8U), PAL_MODE_ALTERNATE(7));
    palSetLineMode(PAL_LINE(GPIOD, 9U), PAL_MODE_ALTERNATE(7));
    sdStart(&SERIAL_DRIVER, &cubley_wp_serial_cfg);

    // Bring up USB CDC as an independent console channel. Wire protocol
    // remains bound to SERIAL_DRIVER (SD3 / USART3) via serialcfg.h.
    chThdCreateStatic(
        waUsbCdcInitThread,
        sizeof(waUsbCdcInitThread),
        NORMALPRIO + 2,
        UsbCdcInitThread,
        NULL);

    osThreadCreate(osThread(ReceiverThread), NULL);
    osKernelStart();

    // Keep booter alive without toggling any GPIO heartbeat.
    while (true)
    {
        osDelay(1000);
    }
}

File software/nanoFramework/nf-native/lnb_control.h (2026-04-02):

/**
 * @file lnb_control.h
 * @brief LNB (Low Noise Block) Control for LNBH26PQR via I2C
 * 
 * The LNBH26PQR is controlled via I2C interface:
 * - Voltage selection (13V/18V) for polarization
 * - 22kHz tone for band selection
 * - Current limiting and protection
 * 
 * I2C Address: 0x08 (7-bit address)
 * I2C Bus: I2C1 (PB6=SCL, PB7=SDA)
 * 
 * Register Map:
 * - Register 0x00: Control register (VSEL, Tone, Enable, etc.)
 * - Register 0x01: Status register (Overcurrent, Temperature, etc.)
 */

#ifndef LNB_CONTROL_H
#define LNB_CONTROL_H

#include <hal.h>
#include <ch.h>
#include <stdint.h>
#include <stdbool.h>

#ifdef __cplusplus
extern "C" {
#endif

/* LNBH26PQR I2C Configuration */
#define LNBH26_I2C_ADDR             0x08        // 7-bit I2C address
#define LNBH26_REG_CONTROL          0x00        // Control register
#define LNBH26_REG_STATUS           0x01        // Status register

/* Control Register Bits */
#define LNBH26_CTRL_EN              (1 << 0)    // Enable LNB power
#define LNBH26_CTRL_VSEL            (1 << 1)    // Voltage select (0=13V, 1=18V)
#define LNBH26_CTRL_TONE            (1 << 2)    // 22kHz tone enable
#define LNBH26_CTRL_DISEQC          (1 << 3)    // DiSEqC mode enable
#define LNBH26_CTRL_ILIM_600MA      (0 << 4)    // Current limit 600mA
#define LNBH26_CTRL_ILIM_400MA      (1 << 4)    // Current limit 400mA

/* Status Register Bits */
#define LNBH26_STAT_OCP             (1 << 0)    // Overcurrent protection triggered
#define LNBH26_STAT_OTP             (1 << 1)    // Over-temperature protection
#define LNBH26_STAT_VMON            (1 << 2)    // Voltage monitor

/* LNB Voltage Selection */
typedef enum {
    LNB_VOLTAGE_13V = 0,    // Vertical polarization
    LNB_VOLTAGE_18V = 1     // Horizontal polarization
} lnb_voltage_t;

/* LNB Polarization (maps to voltage) */
typedef enum {
    LNB_POL_VERTICAL = 0,   // 13V
    LNB_POL_HORIZONTAL = 1  // 18V
} lnb_polarization_t;

/* LNB Band Selection */
typedef enum {
    LNB_BAND_LOW = 0,       // 10.7-11.7 GHz (no 22kHz tone)
    LNB_BAND_HIGH = 1       // 11.7-12.75 GHz (22kHz tone enabled)
} lnb_band_t;

/* LNB Configuration */
typedef struct {
    I2CDriver *i2c_driver;      // I2C driver (I2CD1)
    uint8_t i2c_addr;           // I2C address (0x08)
    lnb_voltage_t voltage;      // Current voltage setting
    bool tone_enabled;          // Current tone state
    bool enabled;               // LNB power enabled
    uint8_t control_reg;        // Shadow of control register
} lnb_handle_t;

/* Status codes */
typedef enum {
    LNB_OK = 0,
    LNB_ERROR_INVALID_PARAM = 1,
    LNB_ERROR_NOT_INITIALIZED = 2,
    LNB_ERROR_I2C = 3
} lnb_status_t;

/**
 * @brief Initialize LNB control
 * @param hlnb LNB handle
 * @param i2c_driver I2C driver (I2CD1)
 * @param i2c_addr I2C address (0x08)
 * @return LNB_OK on success
 */
lnb_status_t lnb_init(lnb_handle_t *hlnb, 
                      I2CDriver *i2c_driver,
                      uint8_t i2c_addr);

/**
 * @brief Set LNB voltage (13V or 18V)
 * @param hlnb LNB handle
 * @param voltage Voltage selection
 * @return LNB_OK on success
 */
lnb_status_t lnb_set_voltage(lnb_handle_t *hlnb, lnb_voltage_t voltage);

/**
 * @brief Set LNB polarization (convenience function)
 * @param hlnb LNB handle
 * @param polarization Polarization selection
 * @return LNB_OK on success
 */
lnb_status_t lnb_set_polarization(lnb_handle_t *hlnb, lnb_polarization_t polarization);

/**
 * @brief Enable/disable 22kHz tone
 * @param hlnb LNB handle
 * @param enable true to enable, false to disable
 * @return LNB_OK on success
 */
lnb_status_t lnb_set_tone(lnb_handle_t *hlnb, bool enable);

/**
 * @brief Set LNB band (convenience function)
 * @param hlnb LNB handle
 * @param band Band selection
 * @return LNB_OK on success
 */
lnb_status_t lnb_set_band(lnb_handle_t *hlnb, lnb_band_t band);

/**
 * @brief Enable/disable LNB power
 * @param hlnb LNB handle
 * @param enable true to enable, false to disable
 * @return LNB_OK on success
 */
lnb_status_t lnb_set_enable(lnb_handle_t *hlnb, bool enable);

/**
 * @brief Get current voltage setting
 * @param hlnb LNB handle
 * @return Current voltage
 */
lnb_voltage_t lnb_get_voltage(lnb_handle_t *hlnb);

/**
 * @brief Get current tone state
 * @param hlnb LNB handle
 * @return true if tone enabled
 */
bool lnb_get_tone(lnb_handle_t *hlnb);

/**
 * @brief Get current polarization
 * @param hlnb LNB handle
 * @return Current polarization
 */
lnb_polarization_t lnb_get_polarization(lnb_handle_t *hlnb);

/**
 * @brief Get current band
 * @param hlnb LNB handle
 * @return Current band
 */
lnb_band_t lnb_get_band(lnb_handle_t *hlnb);

/**
 * @brief Read status register
 * @param hlnb LNB handle
 * @param status Pointer to store status byte
 * @return LNB_OK on success
 */
lnb_status_t lnb_read_status(lnb_handle_t *hlnb, uint8_t *status);

/**
 * @brief Get global LNB handle (for C# interop)
 * @return Pointer to global handle
 */
lnb_handle_t* lnb_get_global_handle(void);

#ifdef __cplusplus
}
#endif

#endif /* LNB_CONTROL_H */

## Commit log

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2026-02-22 Corrective changes to power regulation: F1, PS1
    [BOM_STOCK.xlsx, diseqc_cntrl.kicad_pcb, diseqc_cntrl.kicad_sch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]
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2026-02-23 Fixed pin conflict: TIM1_CH1/I2C3_SCL
    [diseqc_cntrl.kicad_pcb, diseqc_cntrl_mcu.kicad_sch]
2026-02-23 Bugfix: mcu_check_pins.py reports unlabelled nets as floating
    [mcu_check_pins.py]
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2026-02-23 Add host-side interop contract test coverage
    - Extend test project to include native interop wrapper sources
    - Add W5500/DiSEqC/LNB API contract and enum stability tests
    - Update TODO Phase 2 status and note on-device runtime-test requirement
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2026-03-06 Corrected 3v3 reg component layout
    [diseqc_cntrl.kicad_pcb, diseqc_cntrl.kicad_sch]
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2026-03-31 Fix: VBAT should be connected to VDD
    [diseqc_cntrl.kicad_pcb]
2026-03-31 Fix: Add VBUS sense to MCU for USB DFU
    [diseqc_cntrl.kicad_pcb, diseqc_cntrl_mcu.kicad_sch]
2026-04-02 feat(firmware,tests,build): Add managed deployment, MQTT routing, and bring-up test suite
    Build & Firmware:
    - Fix boardInit() to call stm32_clock_init() for correct PLL/clock setup
    - Add HSI PLL support for boards without HSE oscillator (minimal profile)
    - Add bringup-smoke profile: ChibiOS/HAL + USART3 heartbeat for clock/UART validation
    - Add bringup-hardalive profile: bare-metal register-level blink proof
    - Enable config block in minimal profile for nanoff device details query
    - Update build.sh/build.ps1 with profile support, Docker host bootstrap, and positional arg
    - Update nanoCLR_main.c with explicit USART3 serial config (PB10/PB11, 115200 8N1)
    Managed Deployment & MQTT:
    - Add MqttCo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
    [diseqc_cntrl.kicad_pcb, diseqc_enclosure.scad]
2026-04-02 fix(nanoBooter): use HSI PLL on all profiles — no HSE crystal fitted
    RCC_CR=0x7C83 confirmed via GDB: PLLON=0, HSEON=0. ChibiOS
    stm32_clock_init() was spinning on HSERDY at 0x08002530 because
    mcuconf.h had STM32_HSE_ENABLED TRUE / STM32_PLLSRC_HSE. With no HSE
    crystal the bit never sets, so nanoBooter hangs in clock init and
    never calls LaunchCLR().
    Changes:
    - build/mcuconf.h: HSE_ENABLED FALSE, PLLSRC → HSI, PLLN 336→168
    (HSI 16MHz / PLLM=8 = 2MHz VCO_in × 168 = 336MHz / PLLP=2 = 168MHz)
    - toolchain/build.sh: ENABLE_HSI_PLL default changed from 0→1 so
    every build profile applies the HSI PLL override unconditionally
    - toolchain/build.sh: fixed corrupted shell code (ENABLE_HSI_P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
2026-04-02 fix(build): apply custom mcuconf before profile overrides
    Move /work/build/mcuconf.h copy step earlier so board/profile override blocks
    remain final. Previously mcuconf copy happened after overrides, silently
    clobbering generated settings (RTC source, MAC/USB/profile flags, etc.).
2026-04-02 fix(nanoBooter): disable HAL RTC in booter startup
    nanoBooter does not require RTC. Force HAL_USE_RTC=FALSE for
    nanoBooter halconf generation to avoid early RTC init loops blocking
    handoff to nanoCLR on boards with backup-domain clock/source variance.
    nanoCLR still follows profile RTC setting.
2026-04-02 fix(wire-protocol): generate deterministic serialcfg for each transport
    Always generate common/serialcfg.h explicitly:
    - UART profiles -> SERIAL_DRIVER SD3
    - USB serial profiles -> SERIAL_DRIVER SDU1
    Avoid inheriting reference-board serialcfg defaults or relying on sed replacements
    that may leave an incorrect driver (e.g. SD2), which can break nanoff link.
2026-04-03 fix(uart): force PB10/PB11 AF7 for USART3 before sdStart
    E2002 triage showed USART3 peripheral configured but GPIOB mux registers not
    matching PB10/PB11 AF7 runtime expectation. Add a direct register-level safety
    path in nanoCLR main to enable GPIOB clock and force PB10/PB11 to AF7 before
    starting SERIAL_DRIVER.
2026-04-03 fix(linker): restore non-overlapping CLR/deployment flash layout
    Root cause of intermittent deploy E2002 was linker layout overlap:
    - CLR image occupied flash while deployment started inside CLR region,
    causing disconnects during deployment writes.
    Set explicit STM32F407xG nanoCLR memory layout in generated linker script:
    - flash0: 1M - 16k - 256k (752KB for CLR)
    - deployment: org 0x080C0000, len 256KB
    Validated symbols:
    - __nanoImage_start__ = 0x08004000
    - __nanoImage_end__ = 0x080C0000
    - __deployment_start__= 0x080C0000
    - __deployment_end__ = 0x08100000
2026-04-03 fix(build): full clean on profile change to prevent contaminated binaries
    When switching between build profiles (e.g. bringup-smoke -> minimal or
    vice versa), incremental builds reuse cached .o files from the previous
    profile. This produces binaries whose vector-table reset-handler address
    points outside the new binary, causing an immediate crash on boot with
    no serial output.
    Add profile-change detection: store last profile in .last_profile marker
    file in the CMake build directory. When the profile changes, wipe the
    entire build directory before reconfiguring so all objects are rebuilt
    from scratch with the correct flags and linker script.
2026-04-07 Fix nanoFramework bring-up and deployment flow
2026-04-07 nanoframework bringup: add target overrides and tighten blink diagnostics
    - prefer local target overrides before reference backfill in build flow
    - add STM32 UART io-port override files for USART1/USART3
    - update BlinkBringup to deterministic PA2 1s high/low cycle
    - improve bringup-smoke UART3 pin forcing and echo diagnostics
    - include software TODO/README updates related to bringup
2026-04-08 nanoFramework bring-up: fix GPIOA startup and harden managed deploy tooling
    [target_common.c]
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2026-04-08 vendor all target-overrides; remove ST_STM32F4_DISCOVERY reference dependency
    Vendor the full set of target files previously backfilled at build time
    from the nf-interpreter ST_STM32F4_DISCOVERY reference board into
    nf-native/target-overrides/:
    common/ - Device_BlockStorage.c, usbcfg.c/h
    nanoCLR/ - halconf.h, halconf_nf.h, chconf.h, main.c,
    target_board.h.in, STM32F407xG_CLR.ld
    nanoBooter/ - same set + STM32F407xG_booter.ld
    top-level - mcuconf.h, target_BlockStorage.*,
    target_common.h.in, target_nf_*, target_system_*
    All copy_if_absent() calls in build.sh are now unconditional no-ops.
    NF_STATIC_AUDIT=1 verifies this: build fails if any file would requ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
    [board_diseqc.h, halconf.h, main.c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]
2026-04-08 toolchain: fix compile-blink-test.sh to guarantee package restore for clean builds
    - Forces NuGet restore to project root packages dir
    - Self-heals missing mscorlib, System.Device.Gpio, System.Threading by explicit nuget install if needed
    - Fixes clean-clone build failures due to missing references
    - No functional change for existing trees with populated packages/ cache
    Tested: clean clone, local tree, and Docker container all produce working BlinkBringup.bin
2026-04-08 Fix usb-no-vbus board.h rewrite line skipping
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2026-04-09 Fix USART3 nanoff wire-protocol handle mapping
    [target_common.c]
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2026-04-10 Stabilize UART init and preflight across profiles
    [main.c]
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2026-04-10 Capture board migration, ignore .debug, and document temporary W5500 reset routing
    [lnb_control.cpp, main.c, mcuconf.h]
2026-04-10 Add persistent native error telemetry for W5500 open failures
    [cubley_interop.cpp]
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2026-04-11 Add W5500 PHY status interop and harden checksum fix
    [cubley_interop.cpp]
2026-04-11 W5500 PHY diagnostics: NativeGetVersion/VersionPhyStatus interop, PHYCFGR init, SWD diag script
    - Add NativeGetVersion() [slot 11] and NativeGetVersionPhyStatus() [slot 12]
    to Cubley.Interop; interop checksum updated to 55BA4996
    - w5500_hw_init(): write PHYCFGR=0xF8 (RST|OPMD|OPMDC_ALL_AUTO) after soft-reset
    to request all-capable auto-negotiation; readback opcode 0x43 reports HW/SW mode
    - Add tests/swd_read_w5500_diag.sh: reads g_w5500_bringup_status and
    g_w5500_last_native_error via SWD; full PHYCFGR bitfield decode including
    LNK/SPD/DPX/OPMD/OPMDC with human-readable hints
    - W5500Bringup: LogPhyStatus() uses NativeGetVersionPhyStatus() atomic read
    - Finding: PMODE HW straps overri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
    [cubley_interop.cpp]
2026-04-11 board: enable GPIOB and GPIOC AHB1 clocks in boardInit
    GPIOA was the only port clocked, so any pin on port B or C silently
    failed to drive. PC6 (W5500 reset) and PB10/PB11 (SPI/diagnostic)
    were both deaf to palSetLine/palToggleLine as a result.
    Add GPIOBEN and GPIOCEN alongside the existing GPIOAEN.
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2026-05-05 W5500 bring-up: autoneg works, TCP established, diag cleanup
    Bring the W5500/MQTT interface up end-to-end on M0DMF_CUBLEY_F407.
    Hardware context (recorded for posterity, no PCB respin in this commit):
    - Reverted ad-hoc 75 ohm pulls from 3V3 to PHY-side centre taps CT_1/CT_2 -
    these were never on the WIZnet reference and were loading the TX bias
    network. Real Bob-Smith network (75R+75R+1nF on cable-side CT_3/CT_4) is
    parked for the next PCB revision; bench uses an intermediate switch to
    shorten the cable run.
    Software changes:
    - W5500Bringup/Program.cs:
    * Updated network config to lab subnet (172.17.129.253/24, gw .1, broker
    .132.50:1883, MAC 02:24:C1:00:00:51).
    * ForcePhyMo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
    [cubley_interop.cpp]
2026-05-06 managed: slim MQTT bring-up app with ASCII codec and beacon path
    Program.cs reduced to MQTT-first slim form: sink-interface refactor for
    MqttCommandRouter / MqttConfigCommandProcessor, beacons through Main and
    ConnectToMqtt, rotor/LNB/FRAM call sites parked behind the not-yet-bound
    native registrations.
    Drop nanoFramework.System.Text dependency (firmware lacks the matching
    g_CLR_AssemblyNative_nanoFramework_System_Text table). Add AsciiCodec
    helper and replace all Encoding.UTF8 sites in MqttPacket, MqttClient
    and Program with single-byte ASCII conversions.
    Replace the old facade/injector trio with a self-contained MqttClient
    that drives W5500MqttNetworkChannelCore directly. Add finer-grain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
2026-05-12 Fix CLR startup type resolution and retain regression diagnostics
    - identify ResolveAll failure owner/missing assembly via temporary pointer diagnostics
    - include nanoFramework.Runtime.Events in managed deployment path
    - keep StartupProbe active and add TODO note to remove temporary diagnostics later
    - append bring-up validation results
2026-05-12 Refactor managed interop and startup flow
    - align Cubley.Interop native declarations and assembly metadata
    - adjust DiSEqC managed startup path and LNB native binding usage
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2026-05-13 Add hardware presence probes for W5500, LNBH26, and FRAM
    - Implement StartupProbe.cs with three separate bus-level probes:
    - W5500: SPI-based via NativeOpen/NativeGetVersion
    - LNBH26: I2C1 direct address probe (0x08)
    - FRAM: I2C3 direct address probe (0x50)
    - Probes execute at startup and report bitmap status (0x06 in this board config)
    - Add startup breadcrumb markers (0xD5E1xxxx) for scope/SWD correlation
    - Correct I2C1 pin configuration to PB6/PB7 per board layout
    - Include breadcrumb dwell (75ms per marker) for visibility during bring-up
    - Note: breadcrumb diagnostics to be removed in future cleanup pass
    Probe results confirmed via scope capture of I2C3 FRAM transaction (0x50 writ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
2026-05-13 Reintroduce main app with startup probes and FRAM-safe config load
    - Run one-shot hardware probe at entry and hand off bitmap/capabilities into main app
    - Gate network/MQTT startup on W5500 presence while keeping app loop alive
    - Add HardwareCapabilities model for feature gating
    - Refactor FRAM storage to open block address on demand (avoid multi-handle constructor faults)
    - Re-enable startup FRAM config load with stable backend
    - Remove DHCP key from runtime config, serialization, tests, and docs
    - Update bring-up log with scope evidence reference and include capture image
2026-05-19 Starting v0.4 with FT230 fixes; extra TPs
    [diseqc_cntrl.kicad_pcb, diseqc_cntrl.kicad_sch, diseqc_cntrl_lnbh26pqr.kicad_sch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]
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2026-05-26 Fixed fonts
    [diseqc_cntrl.kicad_pcb]
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2026-05-26 Add end-to-end LNBH26 control path
    Implement native LNB init/status APIs, wire new interop bindings, integrate managed command handling, and add bring-up probe/log checkpoints for hardware validation.
    [cubley_interop.cpp, lnbh26_interop.cpp, lnbh26_native.cpp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]
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2026-06-07 Phase A: Lock baseline build and flash configuration
    - Add docs/debug/PHASE_A_BASELINE.md: canonical Phase A baseline reference
    covering selected build profile (cubley-stable), accurate flash map,
    pinned tooling versions, baseline wiring, host setup assumptions, and
    non-baseline run marking convention.
    - Add --baseline yes|no flag to bringup_log_append.sh: non-baseline entries
    get a [NON-BASELINE] annotation and an explanatory Baseline field.
    - Fix flash map table in docs/debug/MANAGED_DEPLOYMENT.md: correct the
    previously inaccurate sector/size breakdown with the real addresses
    (0x08000000 nanoBooter 16 KB, 0x08004000 nanoCLR 752 KB, 0x080C0000
    deployment 256 KB) and add a poi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
2026-06-07 Phase A baseline: reflect devcontainer as the execution environment
    All dev/build/flash work runs inside the devcontainer; no Docker Compose,
    host-side nanoff, or host-side stlink-tools are required.
    - PHASE_A_BASELINE.md: replace Docker Compose / host-tools tooling table
    with the devcontainer pinned versions (gcc-arm-none-eabi 15.2.rel1,
    cmake 3.31.6); replace host setup assumptions with devcontainer setup
    (open container, USB passthrough); update References to point at
    .devcontainer/ instead of Dockerfile.build.
    - software/nanoFramework/README.md: replace old host prerequisites list
    (apt mono, nanoff install, xbuild shim) with a single devcontainer
    note; remove "Docker build"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
2026-06-07 Address PR review on drift fixture and slot message
2026-06-08 Potential fix for pull request finding
    [main.c]
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2026-06-08 Address PR #59 review: clarify stage/error semantics and markdown formatting
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2026-06-09 Corrected TP20 value
    [diseqc_cntrl.kicad_sch, diseqc_cntrl_lnbh26pqr.kicad_sch, diseqc_cntrl_mcu.kicad_sch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]
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2026-07-14 Bugfix: IC6 pin 6 incorrectly connected to 3v3
    [diseqc_cntrl.kicad_pcb, ethernet.kicad_sch]
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2026-07-15 Fix LNB DMA buffer placement and checkpoint smoke status
    [lnbh26_native.cpp]
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2026-07-15 Fix nanoCLR startup: remove BusyDelay before osKernelStart, enable HAL RNG
    - Remove PulseStatusLed BusyDelay from pre-osKernelStart path. The busy-delay
    after sdStart but before osKernelStart blocked the RTOS from starting, causing
    the wire protocol ReceiverThread to never schedule. Root cause introduced in
    628cc12 when PulseStatusLedBeforeManaged was moved to after sdStart.
    - Restore clean minimal main.c grounded in target-overrides-cubley-base working
    pattern: same 4096-byte thread stacks, no delays before osKernelStart.
    - Add HAL_NF_USE_RNG TRUE to halconf_nf.h to fix clean build failure in
    targetRandom.cpp exposed after cache wipe.
    - Wire protocol confirmed working: NFPKTV1 on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
    [main.c]
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2026-07-15 Fix LNB read-register BYREF marshalling
    - Write LNB BYREF outputs using Dereference()->SetInteger in nf-native interop
    - Keep C5 read-reg trace diagnostics for verification
    - Update FRAM+LNB smoke Program.cs with detailed read-reg trace logging
    [lnbh26_interop.cpp]
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2026-07-16 2026-07-16T21:42Z fix(native): correct LNB status-pair interop dispatch order
    Rationale: NativeReadStatusPair was dispatching to NativeReadRegister due managed/native slot-order drift, causing rc=1 despite healthy hardware reads.
    Changes: align CubleyInteropNative InternalCall declaration order with native method_lookup baseline, remove temporary BYREF register shim, keep native status-pair hardening in lnbh26_native, and retain strict interop guard enforcement.
    [cubley_interop.cpp, lnbh26_interop.cpp, lnbh26_native.cpp]
2026-07-16 Add LNB fault diagnostics and reset-cause logging
    [cubley_interop.cpp]
2026-07-17 Fix COM37 USB CDC console: order native method_lookup by PE MethodDef order
    INTEROP SURFACE CHANGE (2026-07-17)
    Rationale: The nanoFramework MetadataProcessor emits PE MethodDef entries ordered
    ALPHABETICALLY by type name (then declaration order within a type). The runtime
    InternalCall dispatch index IS the PE MethodDef index, so the native method_lookup[]
    must follow that alphabetical-by-type order, not managed source/append order.
    Adding LNBH26Tweaks in 6935427 (sorts before UsbCdcConsole) shifted UsbCdcConsole
    from PE[19-21] to PE[23-25], while the native table kept UsbCdcConsole at [19-21].
    As a result UsbCdcConsole.NativeIsEnabled/NativeReadByte/NativeWrite dispatched to
    LNBH26Tweaks n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
    [cubley_interop.cpp]
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2026-08-11 Replaced 10k pull-up on NRST
    [diseqc_cntrl.kicad_pcb, diseqc_cntrl_mcu.kicad_sch]
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2026-08-13 Corrected thermal/EMC issues
    [diseqc_cntrl.kicad_pcb, diseqc_cntrl.kicad_sch, diseqc_cntrl_lnbh26pqr.kicad_sch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]
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2026-08-24 interop: harden PE-order contract and deployment
    Commit timestamp: 2026-08-24 23:06:22 UTC
    Align the managed and native 26-slot PE-order contract, fail closed on incomplete deployment bundles, and validate checksum updates transactionally to improve runtime stability.
    Validation: source-only interop/deployment regressions, clean managed/native builds, 16-assembly runtime resolution, and hardware breakpoint dispatch at 0x08023d6c.
    [lnbh26_interop.cpp]
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2026-08-25 fix: keep LAN8742 RMII transmit idle low
    [board.h]
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2026-08-26 feat(lnb): improve I2C failure diagnostics
    Preserve ChibiOS I2C error flags across the native boundary and expose readable LNB initialization failures in command output.
    Remove temporary USB CDC heartbeat and health tracing now that console bring-up is stable.
    [lnbh26_native.cpp]
2026-08-26 feat(mqtt): add correlated commands and health state
    Require requester-assigned command IDs, replay duplicate QoS 1 transactions, and publish responses on the response topic.
    Add asynchronous LNB fault and communication events, retained device state, and serialized periodic LNBH26 health checks with failure backoff.
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2026-08-27 Fix per-channel LNB enable handling
    Interop change (2026-08-27): LNBH26.NativeSetEnable now accepts a channel argument in existing slot 7; CubleyNative checksum is B2D08F16.
    Rationale: honor channel B enable commands and report each channel's hardware-backed enabled state in show lnb output.
    [cubley_interop.cpp, lnbh26_interop.cpp, lnbh26_native.cpp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]
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2026-08-28 fix: move DiSEqC timing to hardware timers
    Interop change (2026-08-28): append native frame and tone controls. Rationale: remove CLR scheduling overhead from protocol-critical symbol timing.
    [cubley_interop.cpp, diseqc_transmitter.cpp, halconf.h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]
2026-08-30 fix: establish valid LNB high-band tone state
    Interop behavior change (2026-08-30): LNB band selection now coordinates the existing band InternalCall with native PD12 envelope ownership and can return hardware_error when the carrier resource is unavailable. No method slots or signatures changed.
    Rationale: the LNBH26 internal 22 kHz generator requires EXTM=0, TEN=1, and DSQIN high. The timer-backed DiSEqC path left DSQIN low, allowing the unit to report high band without producing the switching tone. Verify DATA2 readback and restore LNB/DiSEqC state transactionally.
    [diseqc_transmitter.cpp, lnbh26_native.cpp, lnbh26_native.h]
2026-08-30 fix: verify LNB output enable state
    Read DATA1 back after output changes and reject states the LNBH26 did not retain. Retry non-mutating managed reads without reinitializing the device and silently disabling active outputs.
    [lnbh26_interop.cpp, lnbh26_native.cpp]
2026-09-06 feat: add JSON device API v2 with a positioner job model
    Replaces the positional MQTT envelope (`<id> <command line>`) with a JSON
    command contract, and introduces a positioner job resource so that
    long-running movement has a representation other than a busy flag.
    The previous envelope used the operator console grammar as a wire format,
    which coupled the machine API to the CLI: neither could change without
    breaking the other. It also had no way to describe motion in progress —
    `diseqc goto` reported success when the frame was transmitted, and motion
    ended either by watchdog expiry or by the client telling the device it had
    finished, which inverts who knows what.
    Transport and contract: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
2026-09-08 fix: encode DiSEqC GoToX angles canonically
    Use the standard tenth-degree fractional lookup for angular position commands and retain microdegree precision in local position estimates and step calibration. Add focused host vectors, including 36.6 degrees east as E2 4A, and document the bounded test procedure.
2026-09-08 fix: restore required System.Text deployment package
    Declare the package explicitly so clean builds can assemble the deterministic deployment bundle introduced by PR #136.
2026-09-08 fix: hold 18 V during positioner motion
    Raise LNB channel A to horizontal voltage before first-class motor commands, retain it for the motion job, and restore the prior polarization on completion, halt, release, or timeout. Surface rollback and restoration failures in diagnostics.
2026-09-08 fix: align typed positioner state handling
    Use overflow-safe calibrated step arithmetic, enforce the 0..60 stored-position range for typed MQTT commands, and apply step metadata and estimation consistently across command transports.
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2026-09-15 Report DiSEqC positions in USALS terms only
    Keep the GoToX fixed offset, an internal calibration factor, off the network
    surface. Angular jobs now record the protocol-rounded target converted back to
    the signed USALS domain, so REST state (estimated_angle_deg, pending_target_deg)
    and machine-readable show output no longer expose the offset-adjusted motor
    angle. The offset-adjusted commanded angle remains available locally in USB
    `show diseqc detail`.
    Interop surface unchanged; interop guard passes.
2026-09-15 Fail closed instead of clamping out-of-range USALS targets
    Return the computed signed USALS target unchanged so the position estimate
    rejects an out-of-range value and reports an unknown position rather than a
    substituted angle. Adds a regression test for that path.
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2026-10-12 Fix Cubley TLS provisioning and quick start
    Limit target TLS record buffers to fit STM32F407 heap during TLS 1.3 handshakes. Add the validated API client and document the tested firmware, X.509 provisioning, deployment, and trusted connection workflow.
    Hardware validation: repeated TLS 1.3 health/state requests passed with certificate verification; TLS 1.2 was rejected.
2026-10-12 Pin Cubley ChibiOS dependency
    Fetch the validated ChibiOS commit explicitly and direct CMake to the preserved local source cache. This prevents moving stable-21.11.x updates from changing or breaking otherwise identical firmware builds.
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2026-10-14 Serialise newlib heap across ChibiOS threads
    lwIP (MEM_LIBC_MALLOC + MEMP_MEM_MALLOC) and mbedTLS both allocate from
    the newlib heap, from tcpip_thread (NORMALPRIO+2) and the CLR thread
    respectively. The toolchain's newlib retarget locks are empty stubs, so
    malloc/free were unprotected. Under scan load (TLS REST + network
    traffic) a preempted allocation corrupted the heap and zeroed a live TCP
    PCB, tripping LWIP_ASSERT "active pcb->state != CLOSED" in tcp_input.
    Without a debugger that BKPT escalates to HardFault, locks up, and the
    IWDG resets the board ~10 s later: the silent reboots seen during
    wavescope active scans.
    Add target-local __malloc_lock/__malloc_unlock backed by a recursive
    Ch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
